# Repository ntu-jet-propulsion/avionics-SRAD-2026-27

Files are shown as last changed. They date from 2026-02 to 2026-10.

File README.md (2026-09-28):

Layers and stackup
TLB is a 4-layer, 50 × 50 mm PCB.
#	Layer	Material	Thickness	Use
—	Top silkscreen	—	—	Reference designators / labels
—	Top solder mask	—	—	—
1	F.Cu	Copper	0.035 mm	Components + signal routing
—	Prepreg	FR4	0.10 mm	Dielectric
2	In1.Cu	Copper	0.0175 mm	Split +3V3 / +5V power plane
—	Core	FR4	1.24 mm	Dielectric
3	In2.Cu	Copper	0.0175 mm	GND plane
—	Prepreg	FR4	0.10 mm	Dielectric
4	B.Cu	Copper	0.035 mm	Debugging / signal routing
—	Bottom solder mask	—	—	—
	Total		1.565 mm	

Layer strategy
- F.Cu: all components + primary signal routing
- In1.Cu: split power plane containing +3V3 and +5V
- In2.Cu: solid GND plane
- B.Cu: remaining/debug signal routing
Unlike the other board, your TLB deliberately has a power layer, because the design contains both 3.3 V and 5 V circuitry.
Your antenna keepout around the ESP32 must remain clear of routing/copper.
2. Routing rules
Your current PCB rules are:
Rule	TLB value
Minimum clearance	0.20 mm
Minimum track width	0.20 mm
Default signal track	0.25 mm
Power track	0.50 mm
Minimum via diameter	0.50 mm
Default via	0.60 / 0.30 mm
Power via	0.80 / 0.40 mm
Minimum drill	0.30 mm
Copper-edge clearance	0.50 mm
Hole-hole clearance	0.25 mm
Annular width	0.10 mm

Your net classes are:
Default
- Clearance: 0.20 mm
- Track: 0.25 mm
- Via: 0.60 / 0.30 mm
Power
- Clearance: 0.20 mm
- Track: 0.50 mm
- Via: 0.80 / 0.40 mm
- Assigned to +3V3 and +5V
3. Copper weights
Layer	Thickness	Weight
F.Cu	35 µm	1 oz
In1.Cu	17.5 µm	0.5 oz
In2.Cu	17.5 µm	0.5 oz
B.Cu	35 µm	1 oz

This matches the stackup specification you were given: 1 oz outer copper and 0.5 oz inner copper.
4. Connectors
Your TLB has these main external interfaces:
Ref	Connector	Purpose
J1	Power_In, 1×2	+3V3 power input + GND
J2	Light_APRS, 1×4	UART telemetry interface
J3	CAN connector, 1×2	CANH + CANL
J5	Micro-USB	USB interface / VBUS / shield
—	ESP32	Main controller / telemetry and logging processing

J1 — Power input
- Pin 1 → +3V3
- Pin 2 → GND
C2, the 33 µF bulk capacitor, is placed close to J1.
J2 — Light APRS
Pin	Signal
1	+3V3
2	GND
3	TX0
4	RX0

Used as the UART interface to the Light APRS system.
J3 — CAN
Pin	Signal
1	CANH
2	CANL

R4 = 120 Ω CAN termination resistor.
J5 — Micro-USB
- Pin 1 → VBUS
- Pin 5 → GND
- Pin 6 → Shield
- R6 = 0 Ω from shield to GND
- C13 associated with VBUS
- C12 associated with GND
5. Main components
MCU
U2 — ESP32-C3
Main microcontroller for the TLB.
Relevant interfaces:
ESP32 signal	Function
IO21 / TXD	I²C SCL
IO20 / RXD	I²C SDA
IO4	CAN-related
IO5	CAN-related
UART0 TX	TX0 → Light APRS
UART0 RX	RX0 ← Light APRS

The ESP32 operates from +3V3.
There is also an antenna keepout region around the ESP32 antenna.
EEPROM
U3 — 24LC256
256-kbit I²C EEPROM used for non-volatile data storage.
Connections:
- VCC → +3V3
- GND → GND
- SDA → ESP32 SDA
- SCL → ESP32 SCL
Pull-ups:
- R1 = 4.7 kΩ
- R3 = 4.7 kΩ
Decoupling:
- C5 = 0.1 µF
- C6 = 0.1 µF
CAN transceiver
U4 — TJA1051TK/3
Provides the physical-layer CAN interface.
Important power arrangement:
Pin	Function	TLB connection
1	TXD	CANTX
2	GND	GND
3	VCC	+5V
4	RXD	CANRX
5	VIO	+3V3
6	CANL	CANL
7	CANH	CANH
8	S	R2

This is important because the TJA1051TK/3 uses 5 V for VCC, while its logic interface can use 3.3 V through VIO.
Supporting components:
- C7 = 0.1 µF
- C8 = 0.1 µF
- C9 = 0.1 µF
- R2 = 10 kΩ
- R4 = 120 Ω termination
6. TLB component summary
Ref	Component	Function
U2	ESP32-C3	Main MCU
U3	24LC256	EEPROM / non-volatile storage
U4	TJA1051TK/3	CAN transceiver
J1	1×2 Power_In	+3V3 + GND input
J2	1×4 Light_APRS	UART telemetry
J3	1×2 CAN	CANH / CANL
J5	Micro-USB	USB interface
C2	33 µF	Bulk supply capacitor
C3/C4	0.1 µF	ESP32 decoupling
C5/C6	0.1 µF	EEPROM decoupling
C7/C8/C9	0.1 µF	CAN transceiver decoupling
C12/C13	0.1 µF	USB-related capacitors
R1/R3	4.7 kΩ	I²C pull-ups
R2	10 kΩ	CAN transceiver S
R4	120 Ω	CAN termination
R5	10 kΩ	ESP32 EN pull-up
R6	0 Ω	USB shield → GND

7. Interfaces / signal map
This is probably one of the most useful sections to have in your README.
I²C
ESP32 → 24LC256
- SCL → U3 pin 6
- SDA → U3 pin 5
- R1/R3 = 4.7 kΩ pull-ups to +3V3
CAN
ESP32 → TJA1051 → CAN connector
ESP32 CANTX
     ↓
TJA1051 TXD
     ↓
CAN transceiver
     ↓
CANH / CANL
     ↓
J3

and
J3 CANH / CANL
       ↓
TJA1051
       ↓
CANRX / CANTX
       ↓
ESP32

UART / Light APRS
ESP32 UART0 TX → J2 TX0
ESP32 UART0 RX ← J2 RX0

USB
J5 USB
 ├── VBUS
 ├── GND
 └── Shield

8. Power architecture
Your current PCB has:
+3V3
Used by:
- ESP32-C3
- 24LC256
- TJA1051 VIO
- I²C pull-ups
- J2
- various decoupling capacitors
+5V
Used by:
- TJA1051 VCC
GND
- Solid plane on In2.Cu
- GND vias connect component/connector GNDs into the plane.
⚠️ Important unresolved point
Your current PCB has a +5V isolated-copper warning, and we couldn't identify an obvious +5V source from the current connector arrangement:
- J1 supplies +3V3
- J5 VBUS is its own Net-(J5-VBUS) net
- U4 requires +5V at VCC
So this should remain explicitly documented as something to confirm with your team lead, rather than us inventing a power architecture.
9. Dimensions
Specification	TLB
Board width	50.0 mm
Board height	50.0 mm
Thickness	1.565 mm nominal stackup
Layers	4
Component side	Top
Mounting holes	2 × Ø5.0 mm NPTH

Your board outline is:
X = 100 → 150 mm
Y = 60 → 110 mm
giving exactly:
50 × 50 mm
10. Mounting holes
You added:
- 2 × 5 mm NPTH mounting holes
These were added as a team requirement.
The exact hole coordinates aren't in the information I have here, so I would not put coordinates into the README until we read them directly from your PCB file.
11. Protection / design features
Your TLB currently has:
Decoupling
Local 0.1 µF capacitors are placed around:
- ESP32
- EEPROM
- CAN transceiver
- USB section
CAN termination
R4 = 120 Ω between CANH and CANL.
Ground plane
In2.Cu = GND plane, with GND vias from components/connectors.
ESP32 antenna keepout
A dedicated keepout is maintained around the ESP32 antenna region.
USB shield grounding
R6 provides the shield-to-GND connection.

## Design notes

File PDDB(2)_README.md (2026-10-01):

[PDDB.md](https://github.com/user-attachments/files/32892513/PDDB.md)
# PDDB — Power Distribution & Driver Board

A **4-layer, 33.1 × 27.0 mm power board** combining a battery input with fuse, an **LM25085 P-FET buck controller**, an **LM3940 3.3 V LDO**, a **TJA1051 CAN transceiver**, and **two low-side AO3400A MOSFET drivers for nichrome coils**.

> **Status:** ⚠️ Prototype / Pre-Fabrication
> The layout is complete and passes KiCad DRC with **0 errors, 0 warnings and 0 unconnected items**. The **schematic still has functional errors**, though. Read the [Known Issues](#10-known-issues--to-do-before-ordering) section before sending the design for fabrication.

---

## 1. Board Overview

### Key Features

* Battery / power input through a screw terminal (J1) and two 1×4 headers (J2, J5)
* Fused battery path (F1)
* LM25085 constant-on-time P-FET buck controller with CSD25402Q3A P-MOSFET and 10 mΩ current sense
* LM3940 3.3 V low-dropout regulator
* TJA1051T CAN transceiver with on-board 120 Ω termination
* Two AO3400A low-side switches for nichrome coils (J7, J8)
* 4-layer PCB with a dedicated solid GND plane and a VCC power plane
* All components mounted on the top side (single-sided SMT assembly)

### Layout Statistics

| Parameter | Value |
| --- | --- |
| Board size | **33.1 × 27.0 mm** (894 mm²)  |
| Copper layers | 4 |
| Components | 35 |
| Routable nets | 19 (100 % routed) |
| Unrouted nets | 0 |
| Total vias | 63 (6 signal/power, 57 GND) |
| Total track length | ≈ 320 mm |
| DRC errors / warnings | **0 / 0** |
| Schematic parity issues | 0 |
| EDA tool | KiCad 10.0 |

---

## 2. PCB Stackup

The PCB uses a **4-layer stackup** with a nominal finished thickness of **1.6 mm**.

| Layer | Type | Thickness | Purpose |
| --- | --- | ---: | --- |
| Top | F.Cu | 35 µm | Components, signal and power routing, GND pour |
| Inner 1 | In1.Cu | 35 µm | **Solid GND plane** |
| Inner 2 | In2.Cu | 35 µm | **VCC power plane** (nichrome coil supply) + secondary routing |
| Bottom  | B.Cu | 35 µm | Secondary signal routing, GND pour |

### Dielectric Structure

| Material | Thickness |
| --- | ---: |
| Top solder mask | 0.01 mm |
| Prepreg | 0.10 mm |
| FR4 core | 1.24 mm |
| Prepreg | 0.10 mm |
| Bottom solder mask | 0.01 mm |
| **Finished thickness** | **1.60 mm** |

FR4 dielectric assumptions:

* Relative permittivity, εr: **4.5**
* Loss tangent, tan δ: **0.02**

> **Note:** These are KiCad's default 4-layer stackup values. The board file does not store an explicit stackup. Define it in *Board Setup → Physical Stackup* and confirm it with the manufacturer.

### Layer Strategy

Components and most routing are on F.Cu. **In1.Cu is an unbroken GND plane** directly under the top layer, so every top-layer signal has a reference plane immediately beneath it.

This provides:

* Short, low-impedance return paths
* Low loop area in the buck converter's switching path
* Reduced EMI
* Shielding between the top layer and the inner power plane

**In2.Cu is a VCC plane.** VCC is the nichrome coil supply. It reaches J2, J5, J7 and J8 through the plane and through 1.0 mm traces. A single Vbat trace and a single U1-VCC trace also run on In2.

**F.Cu and B.Cu carry GND pours** with island removal. Stitching vias on a ≥ 3.5 mm grid tie the pours to the inner GND plane.

### Routing Rules

| Net class | Nets | Track width | Via (pad / drill) |
| --- | --- | ---: | ---: |
| Power | VCC, J7-Pin2, J8-Pin2 (coil supply and returns) | 1.00 mm | 0.80 / 0.40 mm |
| Supply | Vbat, SW node (D1-K), Vout (C1-Pad1), +3.3 V, J2-Pin1, sense+ | 0.50 mm | 0.60 / 0.30 mm |
| Sense | U1-ISEN | 0.40 mm | 0.60 / 0.30 mm |
| Gnd | GND fan-outs (SMD pad → plane) | 0.40 mm | 0.60 / 0.30 mm |
| Default | CANH, CANL, gate drive, ADJ, feedback | 0.25 mm | 0.60 / 0.30 mm |

| Parameter | Specification |
| --- | --- |
| Minimum clearance | 0.20 mm (0.12 mm local override on U4 pads 1–4) |
| Copper-to-edge | ≥ 0.50 mm |
| Standard via | 0.60 mm pad / 0.30 mm drill |
| Small via | 0.50 mm pad / 0.25 mm drill (3 vias, U1–U4 channel) |
| Minimum drill | **0.20 mm** (U1 footprint thermal vias) |
| Minimum annular ring | 0.125 mm |
| Via type | Through-hole only (no blind / buried vias) |
| Surface finish | **ENIG recommended** |

> **Fabrication note:** U1's library footprint (MSOP-8-1EP with thermal vias) has **0.20 mm drills**, so the board minimum hole size is set to 0.20 mm. Most 4-layer fab services support this, but check before ordering.
>
> **Fabrication note:** The U4 (VSON-8 NexFET) library footprint has a 0.14 mm pad-to-pad gap at 0.65 mm pitch. A 0.12 mm local clearance is applied to those pads only. Confirm that the fab's minimum spacing is ≤ 0.12 mm.

### Surface Finish

**ENIG (Electroless Nickel Immersion Gold)** is recommended. The board has fine-pitch leadless packages (VSON-8, MSOP-8 with exposed pad) that benefit from a flat, consistent surface.

---

## 3. Copper Weight

All four copper layers use **1 oz copper (35 µm)**.

| Layer  | Copper Thickness | Copper Weight |
| --- | ---: | ---: |
| F.Cu | 35 µm | 1 oz |
| In1.Cu | 35 µm | 1 oz |
| In2.Cu | 35 µm | 1 oz |
| B.Cu | 35 µm | 1 oz |

Most of the circuitry carries low current: the controller, LDO, CAN and gate drive.

The **nichrome coil paths** are different. They run VCC → J7/J8 → coil → Q3/Q2 → GND and can carry several amps.

* VCC is carried by the In2 plane plus 1.0 mm traces.
* Drain traces Q3 → J7.2 and Q2 → J8.2 are **1.0 mm wide and only ≈ 3 mm long**.
* A 1.0 mm, 1 oz external trace handles roughly **2.5–3 A at a 10 °C rise** (IPC-2221 estimate).

> **Fabrication note:** If the coil firing current exceeds ≈ 3 A continuous, specify **2 oz outer copper**. Firing pulses are short, which also helps. Some manufacturers default to 0.5 oz on inner layers, so specify **1 oz on all four layers** to match the design.

---

## 4. Connectors and Interfaces

| Ref. | Connector / Interface | Purpose |
| --- | --- | --- |
| **J1** | Phoenix PT 1,5/2-5.0-H, 2-pin screw terminal | Battery input (GND / VBAT) |
| **J2** | 1×4, 2.54 mm header | Battery and input (fused path) |
| **J5** | 1×4, 2.54 mm header | Battery and input (parallel to J2) |
| **J4** | 1×2, 2.54 mm header | CANH / CANL |
| **J7** | 1×2, 2.54 mm header | Nichrome coil 1 (driven by Q3) |
| **J8** | 1×2, 2.54 mm header | Nichrome coil 2 (driven by Q2) |
| **J3** | 1×1, 2.54 mm pin | Unconnected in schematic |
| **J6** | 1×1, 2.54 mm pin | Unconnected in schematic |

### J1 — Battery Terminal

The screw terminal takes the main battery input. Its wire-entry face is flush with the **bottom board edge**, and silkscreen labels **GND** (pin 1) and **VBAT** (pin 2) mark the polarity.

> ⚠️ J1 pin 2 connects to Vbat **directly, without going through F1**. Only the J2/J5 path is fused.

### J2 / J5 — Battery and Input Headers

J2 and J5 are wired in parallel:

* Pin 1 is the battery input. It passes through **F1** to Vbat and also biases the coil-driver gates through R1/R5.
* Pin 2 is the VCC coil supply.
* Pins 3–4 are GND.

### J4 — CAN Bus

J4 provides the external **CANH/CANL** connection to other avionics modules.

A **120 Ω termination resistor (R4)** is fitted, so this board is intended to sit at one end of the CAN bus.

> ⚠️ **Review:** J4 only provides CANH and CANL. A shared ground reference is recommended between CAN nodes. Consider a **3-pin CANH/CANL/GND connector**.

### J7 / J8 — Nichrome Coils

Each coil connects between **VCC (pin 1)** and a **low-side AO3400A drain (pin 2)**. Each MOSFET sits directly beside its connector, keeping the switched loop short.

For flight use, consider replacing the 2.54 mm headers with locking connectors such as **JST-GH** or **Molex Pico-Lock**.

### Deliberately Absent Interfaces

The board currently does not include:

* **Microcontroller interface:** the coil drivers have no logic-level control input (see Known Issues).
* **CAN TXD/RXD connection:** the transceiver's logic pins are not brought out.
* **Mounting holes.**

---

## 5. Functional Blocks and Key Devices

| Ref. | Device | Function | Package |
| --- | --- | --- | --- |
| **U1** | TI LM25085MY | P-FET buck controller | MSOP-8-EP (PowerPAD) |
| **U4** | TI CSD25402Q3A | P-channel MOSFET (buck high-side switch) | VSON-8 3.3 × 3.3 NexFET |
| **Rsen1** | 10 mΩ | Buck current-sense resistor | 2512 |
| **L1** | 1.2 µH | Buck inductor | 7.3 × 7.3 × 4.5 mm |
| **D1** | Schottky | Buck freewheel diode | SOD-523 |
| **C2** | 100 µF | Buck output bulk capacitor | Elec. 6.3 × 5.4 mm |
| **VR1** | TI LM3940IMP-3.3 | 3.3 V LDO | SOT-223 |
| **U2** | NXP TJA1051T | High-speed CAN transceiver | SOIC-8 |
| **Q2/Q3** | AO3400A | N-channel low-side coil switches | SOT-23 |
| **F1** | Fuse | Input protection for the J2/J5 path | 1206 |

### Buck Converter (U1, U4, Rsen1, L1, D1, C2)

The LM25085 drives the CSD25402Q3A P-FET through **PGATE**. Current is sensed across **Rsen1 (10 mΩ)**: the sense+ node goes to ADJ via Radj1/Cadj1, and ISEN connects at Rsen1 pad 1.

Layout notes:

* The gate-drive trace (U1.6 → U4.4) is **3.0 mm** long.
* The ADJ trace is **3.6 mm** long. Radj1/Cadj1 sit right beside U1 pin 1.
* The switch node (U4 drain → D1 → L1) is a short **1.0 mm** copper path.
* C2 sits directly under L1's output pad, and C3 is close by.
* U1's VIN, VCC and ISEN pins escape through three 0.5 mm vias in a 1.6 mm channel between U1 and U4.

> ⚠️ The buck converter is **not functional as drawn** (see Known Issues 1 and 3).

### 3.3 V LDO (VR1, C5, C4)

The LM3940 provides a 3.3 V rail, with **C5 (33 µF)** as output capacitor.

> ⚠️ VR1's input pin is tied to GND in the schematic (see Known Issues 2).

### CAN Transceiver (U2, R4)

U2 sits directly above J4. Its CANL and CANH pins (6 and 7) line up with J4 pins 2 and 1, so the bus traces need no crossings. **R4 = 120 Ω** terminates the bus.

### Nichrome Coil Drivers (Q2, Q3, R1–R3, R5)

| Coil | Connector | MOSFET | Gate resistor | Pulled-to-GND resistor |
| ---- | --- | --- | --- | --- |
| 1 | J7 | Q3 | R5 (10 kΩ) | — |
| 2 | J8 | Q2 | R1 (10 kΩ) | — |

R2 and R3 (10 kΩ) connect **J2-Pin1 directly to GND**, not to the gates (see Known Issues 6).

---

## 6. Protection and Reliability

## Implemented Protection

| Feature | Device / Implementation | Purpose |
| --- | --- | --- |
| Input fuse | F1 (1206) | Protects the J2/J5 battery path |
| Current sensing | Rsen1 + LM25085 ADJ | Buck cycle-by-cycle current limit |
| CAN protection | TJA1051 | Bus-fault tolerance, thermal shutdown |
| CAN termination | R4 = 120 Ω | Bus termination |
| Ground plane | In1.Cu (solid) + F/B GND pours  | Low-impedance return, EMI reduction |
| Power plane | In2.Cu VCC | Low-impedance coil supply |
| Local decoupling | Cadj2/Cadj3, C3, C5 | Supply filtering |

### Fuse

**F1** sits between J2/J5 pin 1 and the Vbat net.

> ⚠️ The J1 screw terminal feeds Vbat **directly and bypasses F1**. Consider moving F1 so it protects all inputs.

### CAN Protection

**U2 — TJA1051T** provides built-in protection against bus faults.

> ⚠️ No external CAN ESD/TVS protection is fitted. Because J4 connects to an external cable, consider adding a CAN TVS (e.g. PESD2CAN).

### Ground and Power Planes

* **In1.Cu** is a solid GND plane. The only openings are via and pad clearances.
* Every SMD ground pad has its **own fan-out via** to In1.
* **F.Cu and B.Cu** carry GND pours, stitched to In1 with vias.
* **In2.Cu** is the VCC (coil supply) plane.

---

## Protection Not Currently Implemented

The following protection features are absent or incomplete:

* ❌ Reverse-polarity protection
* ❌ Fuse on the J1 input path
* ❌ CAN external TVS/ESD protection
* ❌ Gate pull-down resistors on Q2/Q3 (coils could turn on from a floating gate)
* ❌ Gate-voltage clamp on Q2/Q3: AO3400A V<sub>GS</sub> max is ±12 V, and the gates are fed from the battery input
* ❌ Flyback / snubber across the coil outputs
* ❌ Input TVS / transient protection

Review these against the final battery voltage and system requirements.

---

## 7. Board Dimensions

| Parameter | Specification |
| --- | --- |
| Board size | **33.1 × 27.0 mm** |
| Board thickness | **1.6 mm** |
| Board shape | Rectangular |
| Component placement | Top side only |
| Mounting holes | **None** (not in schematic) |

### Connector Locations

Coordinates are pin-1 positions, measured from the **top-left corner** of the PCB:

| Connector | Edge | X | Y |
| --- | --- | ---: | ---: |
| J7 | Right  | 31.3 mm |  1.8 mm |
| J8 | Right  | 31.3 mm |  8.0 mm |
| J5 | Right  | 31.3 mm | 17.6 mm |
| J1 | Bottom |  3.0 mm | 21.0 mm |
| J2 | Bottom | 12.9 mm | 25.2 mm |
| J4 | Bottom | 26.7 mm | 25.2 mm |
| J6 | Inner  | 11.0 mm | 12.6 mm |
| J3 | Inner  | 17.6 mm | 21.5 mm |

> ⚠️ The board has **no mounting holes**. If it has to be mechanically secured, add M2/M2.5 holes. That would make the board larger, roughly +6 mm in each direction for corner holes.

### Tall Components

| Component | Approx. Height |
| --- | ---: |
| J2, J4, J5, J7, J8, J3, J6 (2.54 mm headers) | ≈ 8.5 mm (standard 6 mm mating pin) |
| J1 screw terminal | Refer to Phoenix PT 1,5/2-5.0-H datasheet |
| C2 electrolytic | 5.4 mm |
| L1 inductor | 4.5 mm |

---

## 8. Connector Pin Map

| Connector | Pin | Net | Connected To |
| --- | --- | --- | --- |
| J1 | 1 | GND | Ground plane |
| J1 | 2 | Vbat | U1 VIN, Cadj2, Cadj3, Radj2, F1.1 ⚠️ unfused  |
| J2 / J5 | 1 | J2-Pin_1 | F1 → Vbat; R1, R5 (gates); R2, R3 (to GND) ⚠️ |
| J2 / J5 | 2 | VCC | J7.1, J8.1 (coil supply, In2 plane) |
| J2 / J5 | 3 | GND | Ground plane |
| J2 / J5 | 4 | GND | Ground plane |
| J4 | 1 | CANH | U2 pin 7, R4 |
| J4 | 2 | CANL | U2 pin 6, R4 |
| J7 | 1 | VCC | Coil 1 supply |
| J7 | 2 | J7-Pin_2 | Q3 drain |
| J8 | 1 | VCC | Coil 2 supply |
| J8 | 2 | J8-Pin_2 | Q2 drain |
| J3 | 1 | — | Unconnected ⚠️ |
| J6 | 1 | — | Unconnected ⚠️ |

⚠️ = requires review before fabrication.

---

## 9. Footprint Library

Every footprint comes from the **official KiCad footprint library** (`kicad-footprints`, KiCad 10). DRC reports no library mismatches, so the board copies are identical to the library versions.

| Ref(s) | Footprint | Library Link |
| --- | --- | --- |
| U1 | `Package_SO:MSOP-8-1EP_3x3mm_P0.65mm_EP1.73x1.85mm_ThermalVias` | [kicad_mod](https://gitlab.com/kicad/libraries/kicad-footprints/-/blob/master/Package_SO.pretty/MSOP-8-1EP_3x3mm_P0.65mm_EP1.73x1.85mm_ThermalVias.kicad_mod) |
| U2 | `Package_SO:SOIC-8_3.9x4.9mm_P1.27mm` | [kicad_mod](https://gitlab.com/kicad/libraries/kicad-footprints/-/blob/master/Package_SO.pretty/SOIC-8_3.9x4.9mm_P1.27mm.kicad_mod) |
| U4 | `Package_SON:VSON-8_3.3x3.3mm_P0.65mm_NexFET` | [kicad_mod](https://gitlab.com/kicad/libraries/kicad-footprints/-/blob/master/Package_SON.pretty/VSON-8_3.3x3.3mm_P0.65mm_NexFET.kicad_mod) |
| VR1 | `Package_TO_SOT_SMD:SOT-223` | [kicad_mod](https://gitlab.com/kicad/libraries/kicad-footprints/-/blob/master/Package_TO_SOT_SMD.pretty/SOT-223.kicad_mod) |
| Q2, Q3 | `Package_TO_SOT_SMD:SOT-23` | [kicad_mod](https://gitlab.com/kicad/libraries/kicad-footprints/-/blob/master/Package_TO_SOT_SMD.pretty/SOT-23.kicad_mod) |
| D1 | `Diode_SMD:D_SOD-523` | [kicad_mod](https://gitlab.com/kicad/libraries/kicad-footprints/-/blob/master/Diode_SMD.pretty/D_SOD-523.kicad_mod) |
| L1 | `Inductor_SMD:L_7.3x7.3_H4.5` | [kicad_mod](https://gitlab.com/kicad/libraries/kicad-footprints/-/blob/master/Inductor_SMD.pretty/L_7.3x7.3_H4.5.kicad_mod) |
| C2 | `Capacitor_SMD:CP_Elec_6.3x5.4` | [kicad_mod](https://gitlab.com/kicad/libraries/kicad-footprints/-/blob/master/Capacitor_SMD.pretty/CP_Elec_6.3x5.4.kicad_mod) |
| C5 | `Capacitor_SMD:C_1206_3216Metric` | [kicad_mod](https://gitlab.com/kicad/libraries/kicad-footprints/-/blob/master/Capacitor_SMD.pretty/C_1206_3216Metric.kicad_mod) |
| C1, C3, C4 | `Capacitor_SMD:C_0805_2012Metric` | [kicad_mod](https://gitlab.com/kicad/libraries/kicad-footprints/-/blob/master/Capacitor_SMD.pretty/C_0805_2012Metric.kicad_mod) |
| Cadj1, Cadj2, Cadj3 | `Capacitor_SMD:C_0603_1608Metric` | [kicad_mod](https://gitlab.com/kicad/libraries/kicad-footprints/-/blob/master/Capacitor_SMD.pretty/C_0603_1608Metric.kicad_mod) |
| Rsen1 | `Resistor_SMD:R_2512_6332Metric` | [kicad_mod](https://gitlab.com/kicad/libraries/kicad-footprints/-/blob/master/Resistor_SMD.pretty/R_2512_6332Metric.kicad_mod) |
| R1, R2, R3, R5, R6, R7 | `Resistor_SMD:R_0805_2012Metric_Pad1.20x1.40mm_HandSolder` | [kicad_mod](https://gitlab.com/kicad/libraries/kicad-footprints/-/blob/master/Resistor_SMD.pretty/R_0805_2012Metric_Pad1.20x1.40mm_HandSolder.kicad_mod) |
| R4, Radj1, Radj2 | `Resistor_SMD:R_0603_1608Metric` | [kicad_mod](https://gitlab.com/kicad/libraries/kicad-footprints/-/blob/master/Resistor_SMD.pretty/R_0603_1608Metric.kicad_mod) |
| F1 | `Fuse:Fuse_1206_3216Metric` | [kicad_mod](https://gitlab.com/kicad/libraries/kicad-footprints/-/blob/master/Fuse.pretty/Fuse_1206_3216Metric.kicad_mod) |
| J1 | `TerminalBlock_Phoenix:TerminalBlock_Phoenix_PT-1,5-2-5.0-H_1x02_P5.00mm_Horizontal` | [kicad_mod](https://gitlab.com/kicad/libraries/kicad-footprints/-/blob/master/TerminalBlock_Phoenix.pretty/TerminalBlock_Phoenix_PT-1,5-2-5.0-H_1x02_P5.00mm_Horizontal.kicad_mod) |
| J2, J5 | `Connector_PinHeader_2.54mm:PinHeader_1x04_P2.54mm_Vertical` | [kicad_mod](https://gitlab.com/kicad/libraries/kicad-footprints/-/blob/master/Connector_PinHeader_2.54mm.pretty/PinHeader_1x04_P2.54mm_Vertical.kicad_mod) |
| J4, J7, J8 | `Connector_PinHeader_2.54mm:PinHeader_1x02_P2.54mm_Vertical` | [kicad_mod](https://gitlab.com/kicad/libraries/kicad-footprints/-/blob/master/Connector_PinHeader_2.54mm.pretty/PinHeader_1x02_P2.54mm_Vertical.kicad_mod) |
| J3, J6 | `Connector_PinHeader_2.54mm:PinHeader_1x01_P2.54mm_Vertical` | [kicad_mod](https://gitlab.com/kicad/libraries/kicad-footprints/-/blob/master/Connector_PinHeader_2.54mm.pretty/PinHeader_1x01_P2.54mm_Vertical.kicad_mod) |

Library home: [gitlab.com/kicad/libraries/kicad-footprints](https://gitlab.com/kicad/libraries/kicad-footprints)

> **Board-level modification:** U4 pads 1–4 have a **0.12 mm local clearance** set on the board. The footprint geometry itself is unchanged.

---

# 10. Known Issues / To-Do Before Ordering

> ⚠️ **Do not send the PCB for fabrication until the following issues have been reviewed and resolved.**
> All of them are **schematic** issues. The netlist was deliberately left unchanged during layout so the board stays in sync with the schematic. Fix the schematic, update the PCB from it, and re-route the affected nets.

## 10.1 Critical Functional Issues

### 1. Buck Converter Input Path Is Open

The sense+ node is not connected to **Vbat**. This node is Rsen1 pin 2 / Radj1 pin 2 / Cadj1 pin 1 (`Net-(Cadj1-Pad1)`), so U4's source has no supply and the converter cannot run.

**Action:** Connect the Rsen1 / Radj1 / Cadj1 node to Vbat (the LM25085 VIN side), as in the datasheet's typical application.

---

### 2. LM3940 Input Grounded

VR1 pins 1 and 2 are both on GND, and the tab (pin 4) is unconnected. On the SOT-223 LM3940, **pin 1 is IN**. The +3.3 V rail can never be powered.

**Action:** Connect VR1 pin 1 to the intended input rail (5 V or the buck output) and the tab to GND.

---

### 3. LM25085 FB Unconnected

U1 pin 3 (FB) is unconnected, so the R7/R6/C1 feedback divider does not reach the controller.

**Action:** Connect the R7/R6 junction (`Net-(C1-Pad2)`) to U1 FB.

---

### 4. LM25085 Exposed Pad Unconnected

U1's exposed pad (pin 9) and its thermal vias are not on GND.

**Action:** Tie EP to GND per the datasheet.

---

### 5. CAN Transceiver Supply and Logic

U2 VCC (pin 3) is fed from `Net-(U1-VCC)`. That is the LM25085's VCC gate-drive bias pin, **not a regulated 5 V rail**. The TJA1051 needs **4.5–5.5 V**.

U2's other pins are also open:

* TXD (pin 1) is unconnected
* RXD (pin 4) is unconnected
* S (pin 8) is unconnected

**Action:** Provide a proper 5 V supply with local decoupling. Bring TXD/RXD to a controller. Tie S to GND for normal mode, or drive it.

---

### 6. Coil Driver Gate Network

R2 and R3 are connected **from J2-Pin1 to GND**, not from the gates to GND. As drawn:

* Q2/Q3 gates are pulled to the battery input through R1/R5, with no pull-down, so both coils energise whenever J2/J5 pin 1 is live.
* The AO3400A gate rating (±12 V) can be exceeded on a higher-voltage battery.

**Action:** Confirm the intended control scheme. Most likely R2/R3 should be gate pull-downs, and the gates should be driven by a logic-level control signal. Add gate clamping if the battery voltage exceeds 12 V.

---

### 7. Unfused J1 Input

J1 pin 2 feeds Vbat directly, bypassing F1.

**Action:** Route all battery inputs through the fuse.

---

## 10.2 Design Review Items

### C4 Shorted to Ground

C4 has both pads on GND, so it does nothing.

**Action:** Fix its connection or mark it **DNP**.

### Freewheel Diode Rating

D1 is in a **SOD-523** package, which is only rated for low current.

**Action:** Check D1's current rating against the buck converter's load current. A SOD-123F/SMA Schottky may be needed.

### Unconnected Pins J3 / J6

J3 and J6 have no net.

**Action:** Assign their intended function or remove them.

### Unspecified Values

The following values need confirming:

* R7: value shown as `R_Small_US`
* F1: rating not specified
* D1: part number not specified

### Mounting

No mounting holes are present.

**Action:** Add them if the board must be mechanically fixed.

---

# 11. PCB Housekeeping

Before generating manufacturing files:

* [ ] Define the physical stackup explicitly in *Board Setup* (currently KiCad defaults).
* [ ] Add mounting holes if required.
* [ ] Re-run placement and routing for the nets that change after the schematic fixes.
* [ ] Verify silkscreen labels. Refdes for U1, R3, Radj1/2 and Cadj1/2 are on F.Fab only (no room on silk).
* [ ] Check component courtyard clearance (currently 0 violations).
* [ ] Run **Electrical Rules Check (ERC)**.
* [ ] Run **Design Rules Check (DRC)** (currently 0 errors / 0 warnings).
* [ ] Refill all zones before plotting.
* [ ] Generate and inspect Gerbers and drill files before fabrication.

---

# 12. Pre-Fabrication Checklist

### Electrical

* [ ] Buck input path (sense+ → Vbat) connected
* [ ] Buck FB connected and output voltage verified
* [ ] LM25085 exposed pad tied to GND
* [ ] LM3940 input / tab corrected
* [ ] CAN transceiver 5 V supply provided
* [ ] CAN TXD/RXD/S connected
* [ ] CAN termination verified
* [ ] Coil gate drive and pull-downs corrected
* [ ] Gate-voltage rating checked against battery voltage
* [ ] All inputs fused
* [ ] D1 current rating verified
* [ ] Protection requirements reviewed

### PCB

* [ ] Stackup confirmed with manufacturer
* [ ] 1 oz copper specified on all layers (2 oz outer if coil current > ~3 A)
* [ ] 0.20 mm minimum drill supported by fab
* [ ] 0.12 mm minimum spacing (U4 pads) supported by fab
* [ ] Surface finish specified (ENIG)
* [ ] Board dimensions verified (33.1 × 27.0 mm)
* [ ] Mounting holes added or confirmed not required
* [ ] Connector footprints verified
* [ ] Component clearances checked
* [ ] DRC passed
* [ ] ERC passed

### Documentation

* [ ] BOM updated
* [ ] Part numbers verified
* [ ] Connector specifications confirmed
* [ ] Revision number updated
* [ ] Schematic revision updated
* [ ] PCB revision updated
* [ ] README updated
* [ ] Gerbers generated
* [ ] Gerbers reviewed

---

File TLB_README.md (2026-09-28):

# TLB 

A **4-layer, 50 × 50 mm PCB** designed around an **ESP32-C3**. The TLB provides UART telemetry, CAN communication, non-volatile EEPROM storage, USB connectivity, and regulated 3.3 V / 5 V power domains.

> **Status:** Prototype / Pre-Fabrication
> Review the [Power Architecture](#8-power-architecture) section before fabrication, particularly the unresolved +5 V supply for the CAN transceiver.

---

# 1. Layers and Stackup

The TLB is a **4-layer PCB** with a nominal finished thickness of **1.565 mm**.

| Layer | Material | Thickness | Purpose |
| --- | --- | ---: | --- |
| Top silkscreen | — | — | Reference designators and labels |
| Top solder mask | — | — | Component-side protection |
| **1 — F.Cu** | Copper | 0.035 mm | Components and primary signal routing  |
| Prepreg | FR4 | 0.10 mm | Dielectric |
| **2 — In1.Cu** | Copper | 0.0175 mm | Split **+3V3 / +5V power plane** |
| Core | FR4 | 1.24 mm | Dielectric |
| **3 — In2.Cu** | Copper | 0.0175 mm | **Solid GND plane** |
| Prepreg | FR4 | 0.10 mm | Dielectric |
| **4 — B.Cu** | Copper | 0.035 mm | Debugging and secondary signal routing |
| Bottom solder mask | — | — | Bottom-side protection |
| **Total** | | **1.565 mm** | |

### Layer Strategy

* **F.Cu:** Components and primary signal routing
* **In1.Cu:** Split power plane containing **+3V3** and **+5V**
* **In2.Cu:** Solid **GND** plane
* **B.Cu:** Secondary/debug signal routing

Unlike a board using both inner layers as ground, the TLB deliberately uses **In1.Cu as a power plane** because the design contains both 3.3 V and 5 V circuitry.

### ESP32 Antenna Keepout

A dedicated antenna keepout is maintained around the ESP32.

> ⚠️ **Do not route signals or place copper/components inside the ESP32 antenna keepout region.** Maintaining this clearance is important for reliable RF performance.

---

# 2. Routing Rules

The current PCB design uses the following routing constraints:

| Rule | TLB Value |
| --- | ---: |
| Minimum clearance | 0.20 mm |
| Minimum track width | 0.20 mm |
| Default signal track | 0.25 mm |
| Power track | 0.50 mm |
| Minimum via diameter | 0.50 mm |
| Default via | 0.60 / 0.30 mm |
| Power via | 0.80 / 0.40 mm |
| Minimum drill | 0.30 mm |
| Copper-to-edge clearance | 0.50 mm |
| Hole-to-hole clearance | 0.25 mm |
| Minimum annular width | 0.10 mm |

## Net Classes

### Default

| Parameter | Value |
| --- | ---: |
| Clearance | 0.20 mm |
| Track width | 0.25 mm |
| Via | 0.60 / 0.30 mm |

### Power

| Parameter | Value |
| --- | ---: |
| Clearance | 0.20 mm |
| Track width | 0.50 mm |
| Via | 0.80 / 0.40 mm |
| Assigned nets | +3V3, +5V |

---

# 3. Copper Weights

The PCB uses **1 oz outer copper** and **0.5 oz inner copper**.

| Layer  | Thickness | Copper Weight |
| --- | ---: | ---: |
| F.Cu | 35 µm | **1 oz** |
| In1.Cu | 17.5 µm | **0.5 oz** |
| In2.Cu | 17.5 µm | **0.5 oz** |
| B.Cu | 35 µm | **1 oz** |

This matches the intended PCB fabrication stackup.

---

# 4. Connectors and External Interfaces

The TLB provides the following main external interfaces:

| Ref. | Connector | Purpose |
| --- | --- | --- |
| **J1** | 1×2 `Power_In` | +3V3 power input and GND |
| **J2** | 1×4 `Light_APRS`  | UART telemetry interface |
| **J3** | 1×2 CAN connector | CANH and CANL |
| **J5** | Micro-USB | USB, VBUS and shield |
| — | ESP32-C3 | Main controller and telemetry processor |

## J1 — Power Input

| Pin | Signal |
| --- | --- |
| 1 | +3V3 |
| 2 | GND |

**C2 = 33 µF** provides bulk capacitance close to the power input.

---

## J2 — Light APRS

| Pin | Signal |
| --- | --- |
| 1 | +3V3 |
| 2 | GND |
| 3 | TX0 |
| 4 | RX0 |

J2 provides the UART interface to the **Light APRS** system.

---

## J3 — CAN

| Pin | Signal |
| --- | --- |
| 1 | CANH |
| 2 | CANL |

**R4 = 120 Ω** provides CAN bus termination.

---

## J5 — Micro-USB

The USB interface provides:

* **VBUS**
* **GND**
* **USB shield**

Current connections:

| USB Signal | Connection |
| --- | --- |
| VBUS | Net-(J5-VBUS) |
| GND | GND |
| Shield | R6 → GND |

Additional components:

* **R6 = 0 Ω** — USB shield to GND
* **C13 = 0.1 µF** — VBUS-related capacitor
* **C12 = 0.1 µF** — GND-related capacitor

---

# 5. Main Components

## 5.1 ESP32-C3 — U2

The **ESP32-C3** is the main microcontroller for the TLB.

It handles:

* Telemetry processing
* UART communication
* CAN communication
* EEPROM access
* Data processing and logging

The ESP32 operates from the **+3V3** rail.

### Relevant Interfaces

| ESP32 Signal | Function |
| --- | --- |
| IO21 / TXD | I²C SCL |
| IO20 / RXD | I²C SDA |
| IO4 | CAN-related |
| IO5 | CAN-related |
| UART0 TX | TX0 → Light APRS |
| UART0 RX | RX0 ← Light APRS |

> The ESP32 antenna keepout must remain free of copper, routing and components.

---

## 5.2 EEPROM — U3

**U3 — 24LC256**

The 24LC256 is a **256-kbit I²C EEPROM** used for non-volatile data storage.

### Connections

* VCC → +3V3
* GND → GND
* SDA → ESP32 SDA
* SCL → ESP32 SCL

### Supporting Components

| Component |  Value | Function |
| --- | -----: | --- |
| R1 | 4.7 kΩ | I²C pull-up |
| R3 | 4.7 kΩ | I²C pull-up |
| C5 | 0.1 µF | Decoupling  |
| C6 | 0.1 µF | Decoupling  |

---

## 5.3 CAN Transceiver — U4

**U4 — TJA1051TK/3**

The TJA1051TK/3 provides the physical-layer interface between the ESP32 and the CAN bus.

### Pin Connections

| Pin | Function | TLB Connection |
| --: | --- | --- |
| 1 | TXD | CANTX |
| 2 | GND | GND |
| 3 | VCC | +5V |
| 4 | RXD | CANRX |
| 5 | VIO | +3V3 |
| 6 | CANL | CANL |
| 7 | CANH | CANH |
| 8 | S | R2 |

### Power Architecture

The TJA1051TK/3 uses:

* **+5V for VCC**
* **+3V3 for VIO**

This allows the CAN transceiver to interface with the 3.3 V ESP32 logic while operating its main supply from 5 V.

### Supporting Components

| Component |  Value | Function |
| --- | -----: | --- |
| C7 | 0.1 µF | Decoupling |
| C8 | 0.1 µF | Decoupling |
| C9 | 0.1 µF | Decoupling |
| R2 |  10 kΩ | CAN transceiver S |
| R4 |  120 Ω | CAN termination |

---

# 6. Component Summary

| Ref. | Component | Function |
| --- | --- | --- |
| **U2** | ESP32-C3 | Main MCU |
| **U3** | 24LC256 | Non-volatile EEPROM |
| **U4** | TJA1051TK/3 | CAN transceiver |
| **J1** | 1×2 Power_In | +3V3 + GND input |
| **J2** | 1×4 Light_APRS | UART telemetry |
| **J3** | 1×2 CAN | CANH / CANL |
| **J5** | Micro-USB | USB interface |
| **C2** | 33 µF | Bulk supply capacitor |
| **C3/C4** | 0.1 µF | ESP32 decoupling |
| **C5/C6** | 0.1 µF | EEPROM decoupling |
| **C7/C8/C9** | 0.1 µF | CAN transceiver decoupling |
| **C12/C13**  | 0.1 µF | USB-related capacitors |
| **R1/R3** | 4.7 kΩ | I²C pull-ups |
| **R2** | 10 kΩ | CAN transceiver S |
| **R4** | 120 Ω | CAN termination |
| **R5** | 10 kΩ | ESP32 EN pull-up |
| **R6** | 0 Ω | USB shield → GND |

---

# 7. Interfaces and Signal Map

## I²C

The ESP32 communicates with the 24LC256 over I²C.

```text
ESP32-C3
   │
   ├── SCL ───────► U3 SCL
   │                 │
   │              R1 = 4.7 kΩ
   │                 │
   │               +3V3
   │
   └── SDA ───────► U3 SDA
                     │
                  R3 = 4.7 kΩ
                     │
                   +3V3
```

---

## CAN

The ESP32 communicates with the external CAN bus through U4.

```text
ESP32 CANTX
     │
     ▼
TJA1051 TXD
     │
     ▼
 CAN Transceiver
     │
     ├────────► CANH ──────► J3
     │
     └────────► CANL ──────► J3
```

The receive path is:

```text
J3 CANH / CANL
      │
      ▼
TJA1051
      │
      ▼
ESP32 CANRX
```

**R4 = 120 Ω** provides CAN termination between CANH and CANL.

---

## UART / Light APRS

```text
ESP32 UART0 TX ─────► J2 TX0

ESP32 UART0 RX ◄───── J2 RX0
```

J2 also provides +3V3 and GND.

---

## USB

```text
J5 Micro-USB
   │
   ├── VBUS
   ├── GND
   └── Shield
          │
        R6 = 0 Ω
          │
         GND
```

---

# 8. Power Architecture

The TLB contains the following power domains:

## +3V3

The +3V3 rail supplies:

* ESP32-C3
* 24LC256
* TJA1051 VIO
* I²C pull-ups
* J2
* Local decoupling capacitors

## +5V

The +5V rail is intended to supply:

* **TJA1051 VCC**

## GND

Ground is implemented primarily through the **In2.Cu solid ground plane**.

Ground vias connect component and connector ground pins to the plane.

---

## ⚠️ +5V Supply — To Be Confirmed

The current PCB contains a **+5V copper region**, but the source of the +5V rail is not clearly defined in the current connector arrangement.

Currently:

* **J1** provides +3V3
* **J5 VBUS** is on `Net-(J5-VBUS)`
* **U4 VCC** requires +5V

Therefore, the source and regulation path for +5V must be confirmed before fabrication.

> **Action required:** Confirm with the team whether +5V is generated elsewhere, supplied through USB VBUS, or requires an onboard regulator.

Do **not** assume the +5V power architecture is complete until this has been verified.

---

# 9. Board Dimensions

| Specification | TLB |
| --- | ---: |
| Board width | **50.0 mm** |
| Board height | **50.0 mm** |
| Nominal thickness | **1.565 mm** |
| Number of layers  | **4** |
| Component side | Top |
| Mounting holes | **2 × Ø5.0 mm NPTH** |

### Board Outline

The PCB outline is:

```text
X = 100 → 150 mm
Y = 60 → 110 mm
```

Therefore:

**Board size = 50 × 50 mm**

---

# 10. Mounting

The TLB currently contains:

* **2 × Ø5.0 mm non-plated through holes (NPTH)**

Verify the final mounting-hole positions and mechanical clearances against the intended enclosure or mounting structure before fabrication.

---

# 11. Protection and Design Features

## Local Decoupling

Local **0.1 µF decoupling capacitors** are provided around:

* ESP32-C3
* 24LC256
* TJA1051
* USB interface

These capacitors provide local high-frequency supply filtering and reduce supply noise.

## CAN Termination

**R4 = 120 Ω** is connected between CANH and CANL.

This provides termination when the TLB is installed at an end of the CAN bus.

> If the TLB is used as an intermediate CAN node, the termination resistor should be made removable or otherwise disabled.

## Ground Plane

**In2.Cu** is configured as a solid GND plane.

Ground vias connect the component and connector ground connections to the plane, providing low-impedance return paths.

## ESP32 Antenna Keepout

A dedicated keepout region is maintained around the ESP32 antenna.

No routing, copper pours or components should be placed within this region.

## USB Shield Grounding

**R6 = 0 Ω** connects the USB shield to GND.

This provides a defined shield-ground connection while allowing the connection to be modified during hardware testing if required.

---

# 12. Pre-Fabrication Checklist

Before sending the TLB for fabrication:

### PCB

* [ ] Confirm 4-layer stackup with PCB manufacturer
* [ ] Confirm 1 oz outer / 0.5 oz inner copper
* [ ] Confirm 1.565 mm finished thickness is supported
* [ ] Verify 50 × 50 mm board outline
* [ ] Verify mounting-hole locations
* [ ] Verify ESP32 antenna keepout
* [ ] Check all connector footprints
* [ ] Run DRC
* [ ] Resolve all critical DRC violations

### Electrical

* [ ] Confirm +3V3 supply
* [ ] Confirm +5V supply source
* [ ] Verify TJA1051 VCC = +5V
* [ ] Verify TJA1051 VIO = +3V3
* [ ] Verify CAN termination
* [ ] Verify I²C pull-ups
* [ ] Verify UART TX/RX connections
* [ ] Verify USB VBUS routing
* [ ] Verify all decoupling capacitors

### Documentation

* [ ] Update schematic revision
* [ ] Update PCB revision
* [ ] Update BOM
* [ ] Confirm connector part numbers
* [ ] Confirm fabrication stackup
* [ ] Confirm unresolved issues are closed
* [ ] Generate and review Gerber files

---

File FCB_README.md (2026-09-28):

# Flight Computer

A **4-layer rocket/UAV flight computer** built around a **Teensy 4.0**. The board integrates redundant inertial and barometric sensing, GNSS, a real-time clock, microSD data logging, CAN communication, and onboard status indicators.

> **Status:** ⚠️ Prototype / Pre-Fabrication
> Review the [Known Issues](#known-issues--to-do-before-ordering) section before sending the design for fabrication.

---

## 1. Board Overview

### Key Features

* **Teensy 4.0** main flight controller
* Redundant IMU and barometric sensing
* High-G accelerometer for launch/deployment events
* GNSS positioning and recovery tracking
* Real-time clock for timestamped data
* microSD flight-data logging
* CAN bus communication
* Onboard buzzer and status LED
* 4-layer PCB with dedicated ground planes
* All components mounted on the top side

---

## 2. PCB Stackup

The PCB uses a **4-layer stackup** with a nominal finished thickness of **1.6 mm**.

| Layer | Type | Thickness | Purpose |
| --- | --- | ---: | --- |
| Top | F.Cu | 35 µm | Components, signal routing, 3.3 V routing, GPS keepout |
| Inner 1 | In1.Cu | 35 µm | **Solid GND plane** |
| Inner 2 | In2.Cu | 35 µm | **Solid GND plane** |
| Bottom  | B.Cu | 35 µm | Signal routing |

### Dielectric Structure

| Material | Thickness |
| --- | ---: |
| Top solder mask | 0.01 mm |
| Prepreg | 0.10 mm |
| FR4 core | 1.24 mm |
| Prepreg | 0.10 mm |
| Bottom solder mask | 0.01 mm |
| **Finished thickness** | **1.60 mm** |

FR4 dielectric assumptions:

* Relative permittivity, εr: **4.5**
* Loss tangent, tan δ: **0.02**

### Layer Strategy

Signal routing is primarily performed on the two outer copper layers, while **both inner layers are solid ground planes**.

This provides:

* Shorter return-current paths
* Lower loop area
* Improved signal integrity
* Reduced EMI
* Better shielding between signal layers

The 3.3 V rail is routed using traces and local copper pours rather than a dedicated power plane.

### Routing Rules

| Parameter | Specification |
| --- | --- |
| Standard trace width | 0.20 mm |
| Via pad diameter | 0.60 mm |
| Via drill | 0.30 mm |
| Via type | Through-hole |
| Blind vias | 1 currently present  |
| Surface finish | **ENIG recommended** |

> **Fabrication note:** A blind via currently exists from Top → In1.Cu at approximately `(245, 29)`. Many low-cost PCB manufacturers do not support blind vias or charge additional fees. Consider converting this to a standard through-hole via before fabrication.

### Surface Finish

**ENIG (Electroless Nickel Immersion Gold)** is recommended because the board contains fine-pitch/LGA sensor packages and benefits from a flat, consistent surface.

---

## 3. Copper Weight

All four copper layers use **1 oz copper**.

| Layer  | Copper Thickness | Copper Weight |
| --- | ---: | ---: |
| F.Cu | 35 µm | 1 oz |
| In1.Cu | 35 µm | 1 oz |
| In2.Cu | 35 µm | 1 oz |
| B.Cu | 35 µm | 1 oz |

The flight computer carries relatively low current, primarily for the Teensy, sensors, GNSS, storage, and communication interfaces. Therefore, **1 oz copper is sufficient for the intended electrical loads**.

The standard 0.20 mm traces should nevertheless be reviewed against the actual current requirements of each power net before fabrication.

> **Fabrication note:** Some manufacturers default to 0.5 oz copper on inner layers. Specify **1 oz copper on all four layers** if the fabricated stackup is required to match the design.

---

# 4. Connectors and Interfaces

| Ref. | Connector / Interface | Purpose |
| --- | --- | --- |
| **J1** | Würth 693072010801 microSD socket | Flight-data storage |
| **J4** | 1×2, 2.54 mm header | CANH / CANL connection |
| — | Teensy 4.0 micro-USB | Power, programming and debugging |

### J1 — microSD

The microSD socket provides non-volatile storage for flight data.

The Teensy communicates with the card using **SPI**, allowing sensor measurements, GNSS data, system status, and other flight information to be logged during operation.

The card can be removed after recovery and read using a standard PC.

### J4 — CAN Bus

J4 provides the external **CANH/CANL** connection to other avionics modules.

Potential CAN-connected systems include:

* Recovery/pyro controller
* Power-management board
* Telemetry system
* Other flight computers or avionics modules

CAN uses differential signalling and provides good noise immunity, making it suitable for inter-board communication within a vehicle.

A **120 Ω termination resistor (R4)** is currently fitted, meaning this board is intended to operate at one end of the CAN bus.

> ⚠️ **Review:** J4 currently provides only CANH and CANL. A shared ground reference is recommended for the connected CAN nodes. Consider changing J4 to a **3-pin CANH/CANL/GND connector**.

### Teensy USB

The Teensy 4.0 micro-USB connection currently provides:

* Board power
* Firmware programming
* Serial debugging
* Development/testing access

> **Important:** USB is currently the **only power input to the board**.

### Deliberately Absent Interfaces

The board currently does not include:

* **External GPS antenna connector** — the SAM-M8Q includes an integrated patch antenna.
* **Dedicated battery connector** — the current design is powered through the Teensy USB connection.
* **Pyro/deployment outputs** — deployment circuitry is not implemented on this board.

For flight use, consider replacing the J4 2.54 mm header with a locking connector such as **JST-GH** or **Molex Pico-Lock**.

---

# 5. Sensor and Monitoring Devices

The flight computer uses multiple sensors to provide redundancy and cover different flight regimes.

| Ref. | Device | Measurement | Interface | Purpose |
| --- | --- | --- | --- | --- |
| **U9**  | Bosch BMI088 | 3-axis acceleration + 3-axis gyro | SPI | Primary IMU |
| **U2**  | Bosch BNO055 | 9-axis IMU + sensor fusion | I²C | Secondary IMU and orientation  |
| **U10** | ADXL375 | ±200 g acceleration | SPI | High-G event detection |
| **U6**  | Bosch BMP390 | Pressure + temperature | I²C | Primary altitude estimation |
| **U12** | Bosch BMP390 | Pressure + temperature | I²C | Redundant altitude measurement |
| **U4**  | u-blox SAM-M8Q | Position, velocity, time | UART | GNSS positioning |
| **U7**  | TI INA226-Q1 | Voltage, current, power | I²C | Power monitoring |
| **IC1** | DS3231 | Real-time clock | I²C | Timestamping |

### BMI088 — Primary IMU

The BMI088 provides:

* 3-axis acceleration
* 3-axis angular velocity
* High vibration tolerance

It is intended as the primary inertial measurement source during flight, particularly during high-vibration conditions.

### BNO055 — Secondary IMU

The BNO055 provides:

* 3-axis acceleration
* 3-axis angular velocity
* 3-axis magnetometer
* Onboard sensor fusion
* Quaternion/Euler orientation output

It provides an independent inertial measurement source and can be used to cross-check the BMI088.

### ADXL375 — High-G Accelerometer

The ADXL375 provides acceleration measurement up to approximately **±200 g**.

It complements the lower-range IMUs by capturing events such as:

* Launch acceleration
* High-G flight events
* Deployment shocks
* Landing impacts

### BMP390 — Barometric Altimeters

Two BMP390 devices are used for **redundant altitude measurement**.

| Device | I²C Address | Role |
| --- | --- | --- |
| U6 | 0x76 | Primary |
| U12 | 0x77 | Secondary |

Using two independent barometers provides an additional measurement source for altitude and apogee detection.

### SAM-M8Q — GNSS

The SAM-M8Q provides:

* Position
* Velocity
* Time

It is primarily used for:

* Recovery location
* Trajectory logging
* Flight-data analysis

> ⚠️ **High-altitude flight note:** Check the receiver's altitude and velocity limitations against the intended flight profile before use.

### INA226-Q1 — Power Monitoring

The INA226 is intended to measure:

* Bus voltage
* Current
* Power

> ⚠️ **Current status:** The INA226 is not currently connected to a shunt or bus. See [Known Issues](#known-issues--to-do-before-ordering).

### DS3231 — Real-Time Clock

The DS3231 provides an accurate real-time reference for timestamping logged flight data.

It is a clock rather than a flight sensor.

---

# 6. Protection and Reliability

## Implemented Protection

| Feature | Device / Implementation | Purpose |
| --- | --- | --- |
| Voltage supervision | TPS389033-Q1 | Monitors 3.3 V rail |
| CAN protection | TJA1051 | CAN bus fault tolerance |
| Ground planes | In1.Cu + In2.Cu | Noise reduction and signal return |
| GPS keepout | PCB rule area | Protects antenna performance |
| Local decoupling | 100 nF–1 µF capacitors  | Supply filtering |
| Pull-ups / biasing  | R14–R17 | Prevents floating control signals |

### Voltage Supervisor

**U8 — TPS389033-Q1**

The supervisor monitors the 3.3 V supply and controls the Teensy's ON/OFF line when the supply falls below the configured threshold.

> ⚠️ The Teensy 4.0 ON/OFF pin is not equivalent to a conventional hardware reset input. Verify that the intended supervisor behaviour is appropriate for the flight application.

### CAN Protection

**U5 — TJA1051**

The CAN transceiver provides built-in protection against bus faults and includes features such as thermal shutdown and TXD dominant-timeout protection.

> ⚠️ No external CAN ESD/TVS protection is currently fitted. Because J4 connects to an external cable, additional CAN protection should be considered.

### Ground Planes

In1.Cu and In2.Cu are maintained as solid ground planes to:

* Provide low-impedance return paths
* Reduce loop area
* Reduce EMI
* Improve signal integrity

### GPS Antenna Keepout

A dedicated keepout region is provided beneath the SAM-M8Q patch antenna to avoid copper, vias, and components interfering with GNSS performance.

---

## Protection Not Currently Implemented

The following protection features are absent or incomplete:

* ❌ Reverse-polarity protection
* ❌ Input fuse/PTC
* ❌ CAN external TVS/ESD protection
* ❌ microSD ESD protection
* ❌ Brown-out energy storage
* ❌ RTC backup battery
* ❌ GNSS backup supply
* ❌ Pyro/deployment protection circuitry

These should be reviewed according to the final system architecture and flight requirements.

---

# 7. Board Dimensions

| Parameter | Specification |
| --- | --- |
| Board size | **110.0 × 56.0 mm** |
| Board thickness | **1.6 mm** |
| Board shape | Rectangular |
| Component placement | Top side only |
| Mounting holes | 4 × Ø3.0 mm NPTH |
| Mounting-hole keepout | Ø6.5 mm |

### Mounting Hole Locations

Coordinates are measured from the **top-left corner** of the PCB:

| Hole | X | Y |
| ---- | ---: | ---: |
| H4 | 3.0 mm |  4.5 mm |
| H2 | 105.0 mm |  4.5 mm |
| H3 | 3.5 mm | 52.5 mm |
| H2 | 106.0 mm | 52.0 mm |

> ⚠️ The mounting holes are currently **not arranged on a perfectly rectangular pattern**. The bottom holes are offset by approximately 0.5–1.0 mm relative to the top holes. Consider standardising the mounting pattern before fabrication.

### Tall Components

| Component  | Approx. Height |
| --- | ---: |
| BZ1 buzzer | 9.5 mm |
| U4 SAM-M8Q | 6.3 mm |
| Teensy 4.0 | Depends on mounting method |

---

# 8. Teensy 4.0 Pin Map

| Teensy Pin | Signal | Connected Device |
| --- | --- | --- |
| 5 | BUZZER | BZ1 / ADXL375 INT1 / BMI088 INT3 ⚠️  |
| 6 | LED | D1 via R11 |
| 7 | ADXL_CS | ADXL375 CS |
| 8, 34 | BMI088 signals | BMI088 ⚠️ |
| 9, 33 | BMI088 INT2 | BMI088 ⚠️ |
| 10 | SD_CS | microSD |
| 11 | MOSI | microSD / ADXL375 |
| 12 | MISO | microSD / ADXL375 |
| 13 | SCK | microSD / ADXL375 |
| 14 (TX3) | GPS_RX | SAM-M8Q |
| 15 (RX3) | GPS_TX | SAM-M8Q |
| 16 (SCL1)  | I2C_SCL | BNO055 / BMP390 ×2 / DS3231 / INA226 |
| 17 (SDA1)  | I2C_SDA | BNO055 / BMP390 ×2 / DS3231 / INA226 |
| 22 (CTX1)  | CAN_TX | TJA1051 |
| 23 (CRX1)  | CAN_RX | TJA1051 |
| 26 (MOSI1) | BMI088_SDI | BMI088 |
| 27 (SCK1)  | BMI088_SCK | BMI088 |
| ON/OFF | nRESET | TPS3890 |
| 3V3 | +3.3 V | Board supply |
| GND | GND | Board ground |

⚠️ = requires review before fabrication.

---

# 9. I²C Address Map

| Device | Address | Configuration  |
| --- | --- | --- |
| BNO055 | 0x29 | COM3 = 3.3 V |
| BMP390 — U6  | 0x76 | SDO = GND |
| BMP390 — U12 | 0x77 | SDO = 3.3 V |
| DS3231 | 0x68 | Fixed |
| INA226 | **Undefined ⚠️** | A0/A1 floating |

---

# 10. Known Issues / To-Do Before Ordering

> ⚠️ **The current PCB should not be sent for fabrication until the following issues have been reviewed and resolved.**

## 10.1 Critical Functional Issues

### 1. GPS Power

The SAM-M8Q is currently powered through **R3 = 4.7 kΩ**.

This is likely to prevent the GPS from receiving sufficient supply current.

**Action:** Replace R3 with **0 Ω** or an appropriate ferrite bead.

---

### 2. GPS VCC_IO and V_BCKP

The following SAM-M8Q pins are currently unconnected:

* VCC_IO
* V_BCKP

**Action:** Connect VCC_IO appropriately and either connect V_BCKP to the intended backup supply or explicitly terminate it according to the application requirements.

---

### 3. CAN Transceiver Power

The TJA1051 currently has unconnected:

* VCC
* VIO
* GND / exposed pad

The design also does not currently provide the required CAN transceiver supply rail.

**Action:** Resolve the CAN power architecture before fabrication.

---

### 4. BMI088 Interface

The BMI088 connections require significant review.

Current concerns include:

* CSB2, SDO1, SDO2 and INT1 sharing a net
* CSB1 tied directly to GND
* SDO lines not correctly connected to the intended SPI MISO path
* INT2 shorting Teensy pins 9 and 33

**Action:** Re-check the complete BMI088 SPI and interrupt wiring against the datasheet and intended Teensy SPI peripheral.

---

### 5. Buzzer / Interrupt Conflict

The buzzer output currently shares a net with:

* ADXL375 INT1
* BMI088 INT3
* Teensy pin 5

This can cause electrical conflicts between the buzzer driver and sensor interrupt outputs.

**Action:** Assign the buzzer and sensor interrupts to independent nets. A transistor driver should also be considered for the buzzer.

---

### 6. ADXL375 Ground Connections

ADXL375 ground pins 4 and 5 are currently unconnected.

**Action:** Connect all required GND pins according to the datasheet.

---

### 7. BNO055 Interface Configuration

The current PS0/PS1 configuration may select an unintended communication protocol.

**Action:** Verify the PS0/PS1 configuration against the desired standard I²C operating mode.

---

### 8. INA226

The INA226 is currently incomplete:

* A0/A1 are floating
* VBUS is unconnected
* IN+ is unconnected
* IN− is unconnected
* No current-sense shunt is implemented

**Action:** Either complete the power-monitoring circuit or remove the INA226 from the design.

---

### 9. DS3231 Backup Supply

The DS3231 VBAT pin is currently floating.

**Action:** Either provide a backup battery or connect VBAT appropriately according to the intended operating mode.

---

## 10.2 Design Review Items

### I²C Pull-Ups

Multiple 4.7 kΩ pull-ups appear on the I²C bus.

The resulting parallel resistance may be unnecessarily low.

**Action:** Populate a single appropriate pull-up pair and mark redundant footprints as **DNP**.

### Unspecified Resistor Values

The following components have incomplete values:

* R5
* R6
* R9
* R10
* R11

**Action:** Specify the required resistance or mark the component as DNP.

### Teensy ON/OFF Behaviour

The TPS3890 drives the Teensy ON/OFF pin.

**Action:** Confirm that the resulting power-off behaviour is acceptable, as the ON/OFF input does not function as a conventional reset pin.

### TPS3890 SENSE Network

R18 = 240 kΩ is connected to the TPS3890 SENSE network.

**Action:** Verify that this resistor does not unintentionally shift the intended voltage threshold.

### Decoupling

Review local decoupling for:

* DS3231
* INA226
* TJA1051
* SAM-M8Q
* microSD

### Passive Package Sizes

The current design uses very small passive packages, including **01005** components and a **0201 LED**.

**Action:** Consider 0402 packages if manual assembly is expected.

---

# 11. PCB Housekeeping

Before generating manufacturing files:

* [ ] Re-annotate mounting holes — duplicate `H2` designators exist.
* [ ] Add/fix missing `H1` designator.
* [ ] Remove stray via around `(132.4, 5.8)`.
* [ ] Remove duplicate GND vias around `(171, 44)`.
* [ ] Verify all mounting-hole locations.
* [ ] Verify all silkscreen labels.
* [ ] Check component courtyard clearance.
* [ ] Run **Electrical Rules Check (ERC)**.
* [ ] Run **Design Rules Check (DRC)**.
* [ ] Resolve all critical DRC/ERC errors.
* [ ] Generate and inspect Gerbers before fabrication.

---

# 12. Pre-Fabrication Checklist

### Electrical

* [ ] Power architecture verified
* [ ] GPS power verified
* [ ] CAN power verified
* [ ] CAN termination verified
* [ ] BMI088 SPI verified
* [ ] BMI088 interrupts verified
* [ ] BNO055 protocol configuration verified
* [ ] ADXL375 grounding verified
* [ ] INA226 completed or removed
* [ ] DS3231 backup supply resolved
* [ ] Buzzer/interrupt conflict resolved
* [ ] Protection requirements reviewed

### PCB

* [ ] Stackup confirmed with manufacturer
* [ ] 1 oz copper specified on all layers
* [ ] Surface finish specified
* [ ] Blind via removed or fabrication capability confirmed
* [ ] Board dimensions verified
* [ ] Mounting pattern finalised
* [ ] Connector footprints verified
* [ ] Component clearances checked
* [ ] DRC passed
* [ ] ERC passed

### Documentation

* [ ] BOM updated
* [ ] Part numbers verified
* [ ] Connector specifications confirmed
* [ ] Sensor list updated
* [ ] Revision number updated
* [ ] Schematic revision updated
* [ ] PCB revision updated
* [ ] README updated
* [ ] Gerbers generated
* [ ] Gerbers reviewed

---

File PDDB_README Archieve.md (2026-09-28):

# PDDB 

## 1. Overview

The **Power Distribution & Driver Board (PDDB)** is a power-management and output-control PCB designed to distribute battery power, provide regulated low-voltage rails, communicate over CAN, and control external loads such as nichrome coils.

The board incorporates:

* Battery/power input connections
* High-current power distribution
* Fused input protection
* Buck-converter voltage regulation
* 3.3 V regulation
* CAN bus communication
* Current sensing
* MOSFET-based load switching
* Nichrome coil outputs
* External signal and ground connections

The design is implemented in **KiCad** and consists of both the schematic and PCB layout.

---

## 2. Project Files

| File | Description |
| --- | --- |
| `PDDB Schematic.kicad_pro` | KiCad project configuration |
| `PDDB Schematic.kicad_sch` | Electrical schematic |
| `PDDB Schematic.kicad_pcb` | PCB layout |
| `PDDB Schematic-backups/`  | KiCad automatic project backups |
| `.history/` | KiCad local history |

### Current Design Version

**Version:** v0.x — Development

> The exact release/version number should be updated when this revision is formally pushed to the repository.

---

# 3. Functional Architecture

The PDDB can be broadly divided into the following functional blocks:

```text
                 ┌──────────────────────┐
Battery Input ──►│ Input Protection     │
                 │ Fuse / Protection    │
                 └──────────┬───────────┘
                            │
                            ▼
                 ┌──────────────────────┐
                 │ Power Distribution   │
                 │ & Current Sensing    │
                 └───────┬───────┬──────┘
                         │       │
              ┌──────────┘       └──────────────┐
              ▼                                 ▼
      ┌───────────────┐                 ┌────────────────┐
      │ Buck Converter│                 │ Load Switching │
      │ LM25085       │                 │ MOSFETs        │
      └───────┬───────┘                 └───────┬────────┘
              │                                 │
              ▼                                 ▼
         Regulated Rails                  Nichrome Coils

              │
              ▼
      ┌───────────────┐
      │ CAN Interface │
      │ TJA1051T      │
      └───────────────┘
```

---

# 4. Power Regulation

## 4.1 Main Buck Converter

The primary switching regulator is:

**U1 — LM25085MY**

The LM25085 is used as the main buck-converter controller.

Associated components include:

| Reference | Value | Function |
| --- | ---: | --- |
| U1 | LM25085MY | Buck regulator controller |
| L1 | 1.2 µH | Output inductor |
| Rsen1 | 10 mΩ | Current-sense resistor |
| C5 | 33 µF | Output filtering |
| C2 | 100 µF | Bulk filtering |
| R6 | 3.32 kΩ | Feedback/control network |
| Radj1 | 2.55 kΩ | Adjustable regulation network |
| Radj2 | 2.55 kΩ | Adjustable regulation network |
| C3 | 470 nF | Filtering/compensation |

The exact regulated output voltage and maximum current should be confirmed against the latest power-budget calculations before fabrication.

---

## 4.2 3.3 V Regulation

**VR1 — LM3940IMP-3.3_NOPB**

The LM3940 is used to provide a regulated **3.3 V rail** for low-voltage circuitry.

Associated capacitor:

* **C4 — 3.3 µF**

The 3.3 V rail is intended for the board's low-voltage electronics and control/interface circuitry.

---

# 5. Input and Protection

The PDDB includes input protection to reduce the risk of damage caused by electrical faults.

## 5.1 Fuse

**F1 — Fuse**

The fuse provides overcurrent protection on the power input.

The final fuse rating should be selected based on:

* Maximum expected operating current
* Normal startup/inrush current
* Nichrome load current
* PCB trace/current capacity
* Connector current rating
* Power supply/battery specifications

**Fuse rating: TBD / confirm before release**

---

## 5.2 Reverse/Transient Protection

The design includes:

**D1 — Schottky diode**

The Schottky diode provides protection within the power-input/control circuitry.

The exact protection behaviour should be verified against the final schematic and intended fault cases before the production release.

---

## 5.3 Bulk and Local Decoupling

The board contains multiple capacitors for:

* Input bulk energy storage
* Switching regulator filtering
* Local supply decoupling
* Noise reduction

Relevant components include:

* C1 — 1.6 nF
* C2 — 100 µF
* C3 — 470 nF
* C4 — 3.3 µF
* C5 — 33 µF
* Cadj1 — 1 nF
* Cadj2 — 1 nF
* Cadj3 — 1 nF

---

# 6. CAN Communication

## CAN Transceiver

**U2 — TJA1051T**

The TJA1051T provides the physical-layer interface for CAN communication.

The board exposes:

* **CANH**
* **CANL**

The schematic also includes:

**R4 — 120 Ω**

This resistor is associated with CAN bus termination.

### CAN Connector

The CAN interface is exposed through the board's connector/interface circuitry.

The final system configuration should determine whether the board is intended to provide a permanent 120 Ω termination or whether termination should be selectable.

---

# 7. Load / Nichrome Control

The PDDB provides switched outputs for nichrome-based loads.

Two dedicated connectors are present:

| Reference | Label | Purpose |
| --- | --- | --- |
| J7 | `nichrome coil` | Nichrome load connection |
| J8 | `nichrome coil` | Nichrome load connection |

The load switching circuitry uses MOSFETs including:

* **Q2 — AO3400A**
* **Q3 — AO3400A**
* **U4 — CSD25402Q3A**

These devices provide electronic switching of the connected loads.

The exact continuous and peak current limits must be verified from:

1. MOSFET SOA/current rating
2. PCB copper capacity
3. Connector rating
4. Thermal performance
5. Nichrome resistance
6. Supply voltage

---

# 8. Connectors

The current schematic contains the following external connectors/interfaces.

| Reference | Label / Value | Purpose |
| --- | --- | --- |
| J1 | `Conn_01x02` | 2-pin external connection |
| J2 | `Battery and input` | Battery/power input |
| J3 | `Conn_01x01_Pin` | Single-pin connection |
| J4 | `Conn_01x02` | 2-pin external connection |
| J5 | `Battery and input` | Battery/power input |
| J6 | `Conn_01x01_Pin` | Single-pin connection |
| J7 | `nichrome coil` | Nichrome load output |
| J8 | `nichrome coil` | Nichrome load output |

### Connector Design Rationale

The connectors are provided to separate the major external interfaces of the PDDB:

* **Battery/input connectors** provide the primary power connection.
* **Nichrome connectors** provide dedicated high-current load connections.
* **2-pin connectors** provide signal/power connections where both signal and return are required.
* **Single-pin connectors** provide dedicated signal/test/auxiliary connections where a separate ground connection is not required at the connector.

> The exact mating connector part numbers should be added to the BOM before the PCB is released for manufacturing.

---

# 9. Current Sensing

The board contains:

**Rsen1 — 10 mΩ**

This low-value shunt resistor is used for current sensing within the power stage.

The shunt allows the voltage developed across the resistor to be used to determine current:

$$
I = \frac{V_{sense}}{R_{sense}}
$$

For the installed 10 mΩ resistor:

$$
I = \frac{V_{sense}}{0.010}
$$

Therefore, a 10 mV voltage drop corresponds to approximately:

$$
I = 1\,A
$$

and a 100 mV drop corresponds to:

$$
I = 10\,A
$$

The final measurable current range depends on the sensing circuitry and ADC/interface used by the overall system.

---

# 10. Sensor / Monitoring Interfaces

The current PDDB design should be treated as a **power and driver board rather than a dedicated sensor board**.

The following monitoring-related functionality is present:

| Function | Component / Interface | Status  |
| --- | --- | --- |
| Current sensing | Rsen1, 10 mΩ shunt | Present |
| CAN communication | U2, TJA1051T | Present |
| Supply voltage monitoring | External/system-dependent | Confirm |
| Temperature sensing | Not explicitly identified in current schematic | TBD |
| Current/voltage ADC | External MCU/system-dependent | TBD |

### Sensor List

Before the README is considered final, the project owner should confirm the complete system-level sensor list.

At minimum, document:

* Current sensor
* Voltage sensor
* Temperature sensor(s), if present
* Any external sensors connected through J1/J3/J4/J6
* CAN-connected sensors, if applicable

**Do not add a sensor to this list unless it is actually implemented or explicitly specified for the final system.**

---

# 11. PCB Stackup

The current KiCad PCB file does not contain a formal fabrication stackup definition.

The current board is therefore documented as:

**PCB type:** TBD
**Number of copper layers:** TBD
**Board thickness:** 1.6 mm nominal in the current KiCad board setup
**Copper weight:** TBD

### Recommended README entry after fabrication specification is confirmed

```text
Layer 1: Top Copper — TBD oz
Layer 2: Bottom Copper — TBD oz

Board thickness: 1.6 mm
Copper weight: TBD
Surface finish: TBD
Solder mask: TBD
Silkscreen: TBD
```

The final stackup should be confirmed with the PCB manufacturer before release.

---

# 12. Copper Weight

The copper weight has not been explicitly specified in the current KiCad PCB file.

**Current status: TBD**

Copper weight should be selected based on the maximum current carried by:

* Battery input traces
* Main power distribution paths
* Nichrome outputs
* Buck-converter power path

High-current traces should also be checked for:

* Trace width
* Temperature rise
* Via current capacity
* Connector current rating
* Copper thickness
* Continuous vs transient current

For the production release, the selected copper weight should be explicitly recorded here.

---

# 13. PCB Dimensions

The final mechanical dimensions should be recorded here once the Edge.Cuts outline has been finalized.

**Current board dimensions: TBD**

Required information:

| Parameter | Value |
| --- | --- |
| Length | TBD mm |
| Width | TBD mm |
| Thickness | 1.6 mm nominal |
| Mounting-hole diameter  | TBD mm |
| Mounting-hole locations | TBD |
| Connector clearance | TBD |
| Component height limit  | TBD |

The mechanical drawing should be checked before fabrication to ensure compatibility with the intended enclosure/system.

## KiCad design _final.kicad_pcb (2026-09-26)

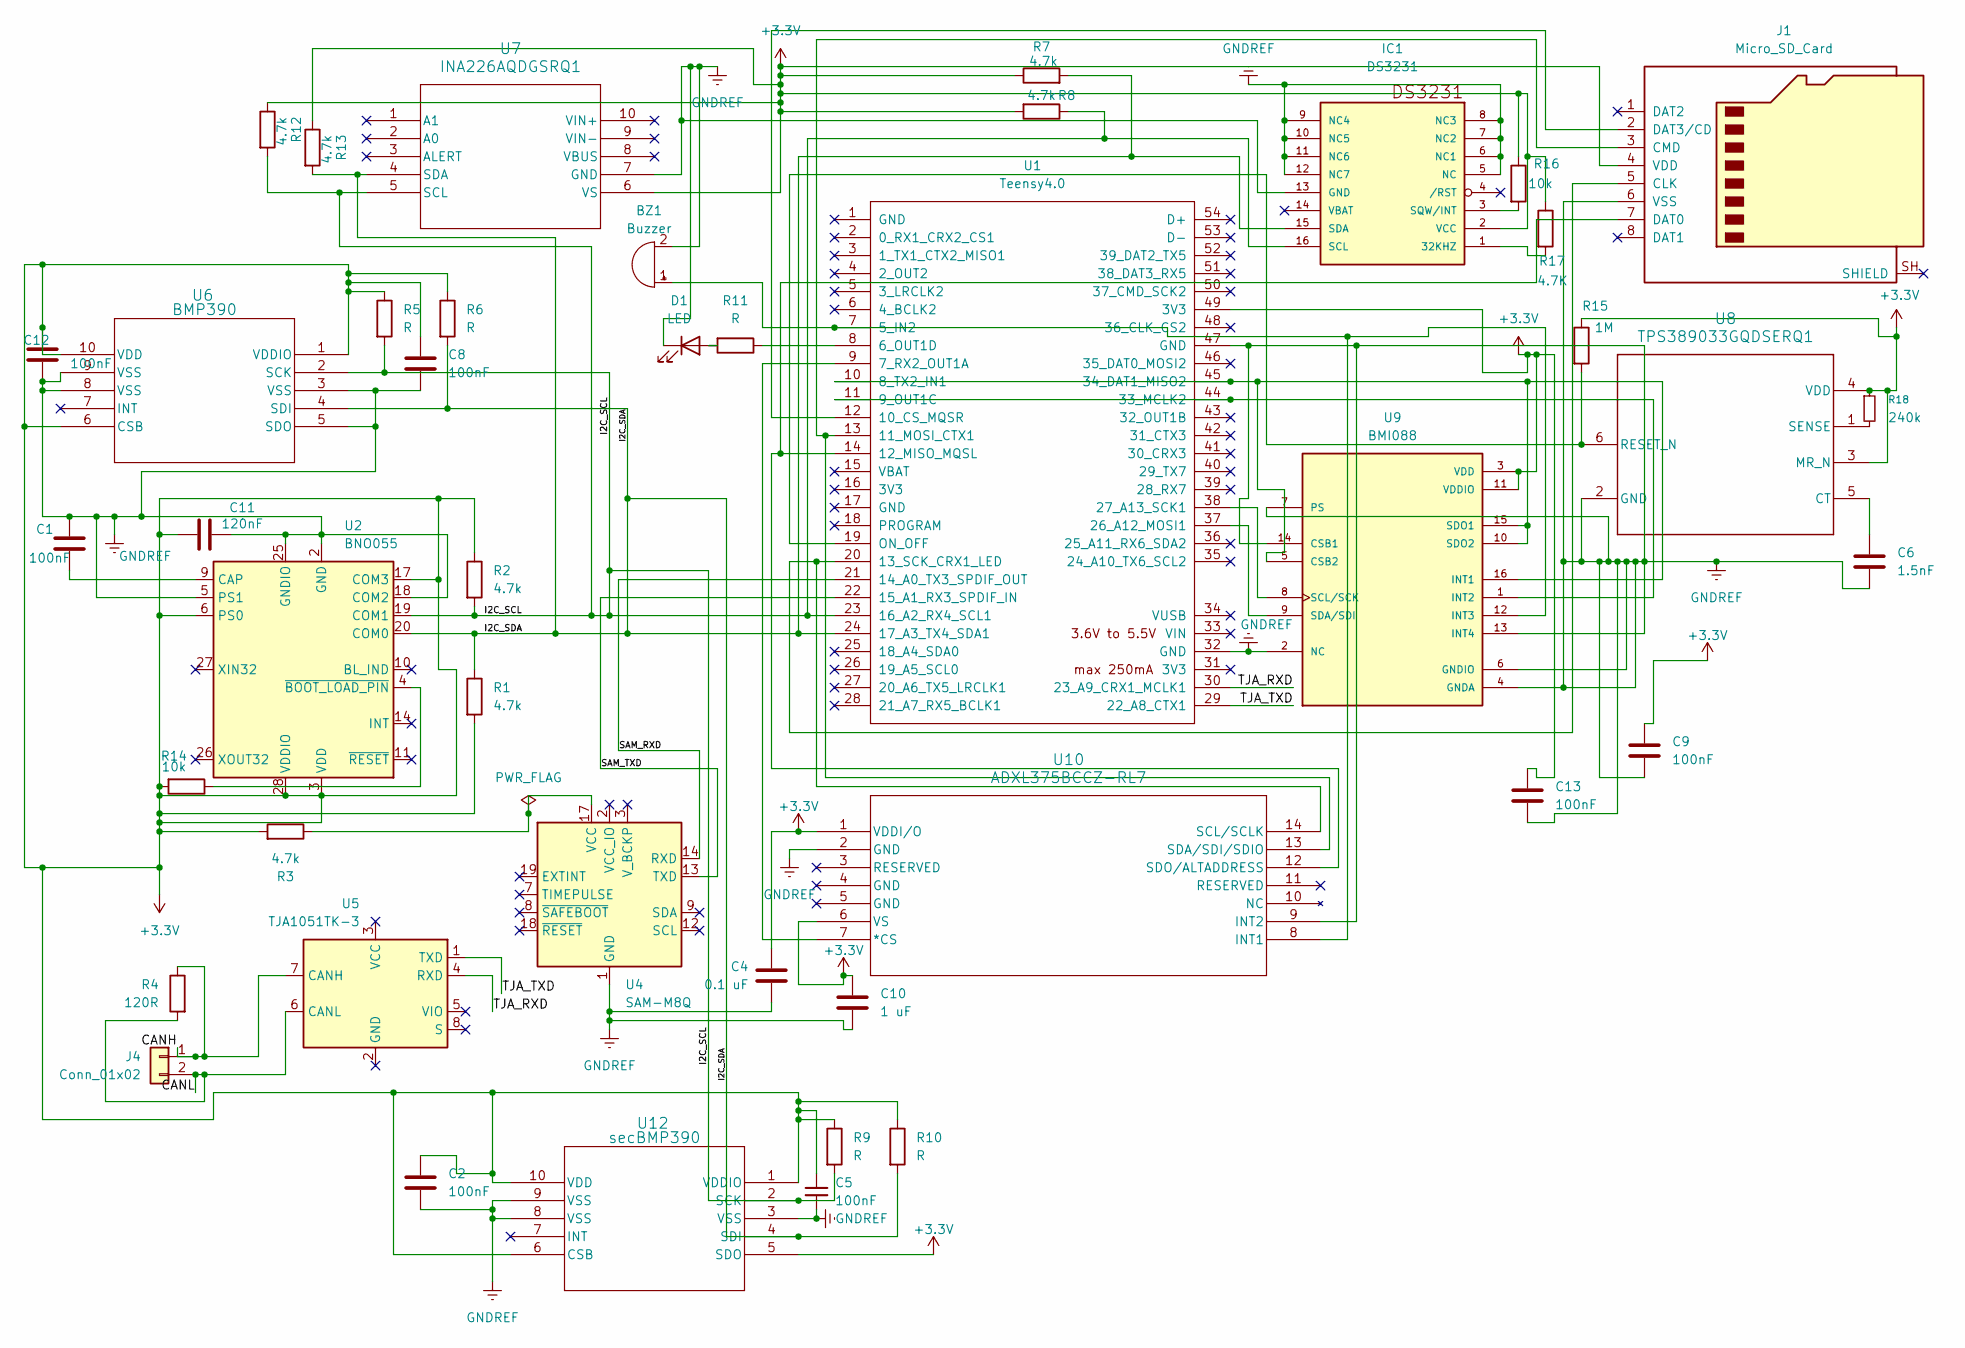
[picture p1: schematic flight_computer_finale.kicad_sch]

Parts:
BZ1: Buzzer; Buzzer_12x9.5RM7.6
C1, C2, C5, C8, C9, C12, C13: 100nF; C_01005_0402Metric
C4: 0.1 uF; C_01005_0402Metric
C6: 1.5nF; C_01005_0402Metric
C10: 1 uF; C_01005_0402Metric
C11: 120nF; C_01005_0402Metric
D1: LED; LED_0201_0603Metric
IC1: DS3231; 21-0042B_16_MXM
J1: Micro_SD_Card; microSD_HC_Wuerth_693072010801
J4: Conn_01x02; PinHeader_1x02_P2.54mm_Vertical
R1, R2, R3, R7, R8, R12, R13: 4.7k; R_01005_0402Metric
R4: 120R; R_01005_0402Metric
R5, R6, R9, R10, R11: R; R_01005_0402Metric
R14, R16: 10k; R_01005_0402Metric
R15: 1M; R_01005_0402Metric
R17: 4.7K; R_01005_0402Metric
R18: 240k; R_01005_0402Metric
U1: Teensy4.0; Teensy40_SMT
U2: BNO055; LGA-28_5.2x3.8mm_P0.5mm
U4: SAM-M8Q; ublox_SAM-M8Q
U5: TJA1051TK-3; HVSON-8-1EP_3x3mm_P0.65mm_EP1.6x2.4mm
U6: BMP390; 10LGA_2X2X0p75_BOS
U7: INA226AQDGSRQ1; DGS10_TEX
U8: TPS389033GQDSERQ1; DSE0006A
U9: BMI088; QFN_BMI085_BOS
U10: ADXL375BCCZ-RL7; LGA_CC-14-1_ADI
U12: secBMP390; 10LGA_2X2X0p75_BOS

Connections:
+3.3V: C2.1, C4.1, C5.1, C8.1, C9.1, C10.1, C11.1, C12.1, C13.1, IC1.2 (VCC), J1.4 (VDD), R1.2, R2.1, R3.2, R5.1, R6.1, R7.1, R8.2, R9.1, R10.1, R12.1, R13.1, R14.2, R15.1, R16.1, R17.1, R18.1, U1.49 (3V3), U2.3 (VDD), U2.6 (PS0), U2.17 (COM3), U2.28 (VDDIO), U6.1 (VDDIO), U6.6 (CSB), U6.10 (VDD), U7.6 (VS), U8.3 (MR_N), U8.4 (VDD), U9.3 (VDD), U9.11 (VDDIO), U10.1 (VDDI/O), U10.6 (VS), U12.1 (VDDIO), U12.5 (SDO), U12.6 (CSB), U12.10 (VDD)
/CANH: J4.1, R4.1, U5.7 (CANH)
/CANL: J4.2, R4.2, U5.6 (CANL)
/I2C_SCL: IC1.16 (SCL), R2.2, R5.2, R8.1, R9.2, R12.2, U1.23 (16_A2_RX4_SCL1), U2.19 (COM1), U6.2 (SCK), U7.5 (SCL), U12.2 (SCK)
/I2C_SDA: IC1.15 (SDA), R1.1, R6.2, R7.2, R10.2, R13.2, U1.24 (17_A3_TX4_SDA1), U2.20 (COM0), U6.4 (SDI), U7.4 (SDA), U12.4 (SDI)
/SAM_RXD: U1.21 (14_A0_TX3_SPDIF_OUT), U4.14 (RXD)
/SAM_TXD: U1.22 (15_A1_RX3_SPDIF_IN), U4.13 (TXD)
/TJA_RXD: U1.30 (23_A9_CRX1_MCLK1), U5.4 (RXD)
/TJA_TXD: U1.29 (22_A8_CTX1), U5.1 (TXD)
GNDREF: BZ1.2 (-), C1.1, C2.2, C4.2, C5.2, C6.2, C8.2, C9.2, C10.2, C11.2, C12.2, C13.2, D1.1 (K), IC1.5 (NC), IC1.6 (NC1), IC1.7 (NC2), IC1.8 (NC3), IC1.9 (NC4), IC1.10 (NC5), IC1.11 (NC6), IC1.12 (NC7), IC1.13 (GND), J1.6 (VSS), U1.32 (GND), U1.47 (GND), U2.2 (GND), U2.5 (PS1), U2.18 (COM2), U2.25 (GNDIO), U4.1 (GND), U4.4 (GND), U4.5 (GND), U4.6 (GND), U4.10 (GND), U4.11 (GND), U4.15 (GND), U4.16 (GND), U4.20 (GND), U6.3 (VSS), U6.5 (SDO), U6.8 (VSS), U6.9 (VSS), U7.7 (GND), U8.2 (GND), U9.2 (NC), U9.4 (GNDA), U9.6 (GNDIO), U9.7 (PS), U9.13 (INT4), U9.14 (CSB1), U10.2 (GND), U10.9 (INT2), U12.3 (VSS), U12.8 (VSS), U12.9 (VSS)
unnamed: BZ1.1 (+), U1.7 (5_IN2), U9.12 (INT3), U10.8 (INT1)
unnamed: D1.2 (A), R11.2
unnamed: IC1.1 (32KHZ), R17.2
unnamed: IC1.3 (SQW/INT), R16.2
unnamed: J1.5 (CLK), U1.20 (13_SCK_CRX1_LED), U10.14 (SCL/SCLK)
unnamed: J1.3 (CMD), U1.13 (11_MOSI_CTX1), U10.13 (SDA/SDI/SDIO)
unnamed: J1.7 (DAT0), U1.14 (12_MISO_MQSL), U10.12 (SDO/ALTADDRESS)
unnamed: J1.2 (DAT3/CD), U1.12 (10_CS_MQSR)
unnamed: R11.1, U1.8 (6_OUT1D)
unnamed: U1.9 (7_RX2_OUT1A), U10.7 (*CS)
unnamed: U1.37 (26_A12_MOSI1), U9.9 (SDA/SDI)
unnamed: U1.38 (27_A13_SCK1), U9.8 (SCL/SCK)
unnamed: U1.11 (9_OUT1C), U1.44 (33_MCLK2), U9.1 (INT2)
unnamed: U1.10 (8_TX2_IN1), U1.45 (34_DAT1_MISO2), U9.5 (CSB2), U9.10 (SDO2), U9.15 (SDO1), U9.16 (INT1)
unnamed: R15.2, U1.19 (ON_OFF), U8.6 (RESET_N)
unnamed: C1.2, U2.9 (CAP)
unnamed: R14.1, U2.4 (~BOOT_LOAD_PIN)
unnamed: R3.1, U4.17 (VCC)
unnamed: C6.1, U8.5 (CT)
unnamed: R18.2, U8.1 (SENSE)

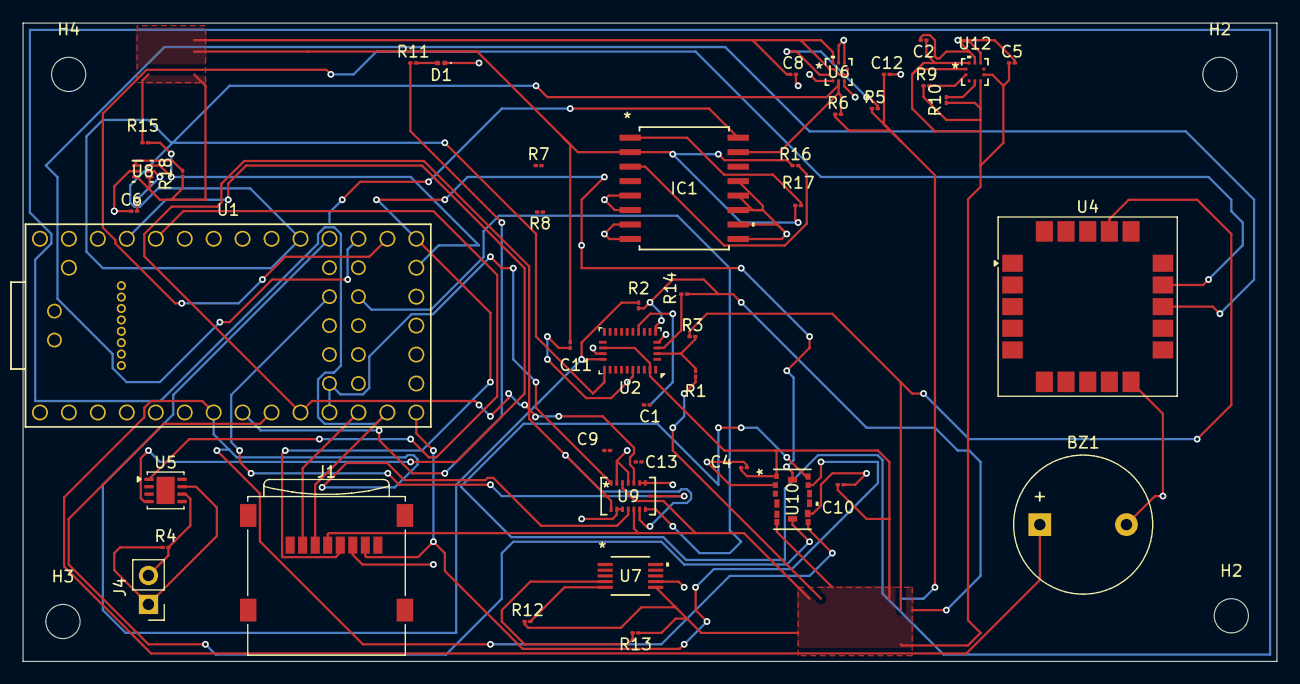
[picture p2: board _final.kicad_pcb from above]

Board: 4 copper layers, 110.0 x 56.0 mm, 48 parts (0 on the bottom side), 30 nets.

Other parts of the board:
H2, H2#2, H3, H4: MountingHole_3mm

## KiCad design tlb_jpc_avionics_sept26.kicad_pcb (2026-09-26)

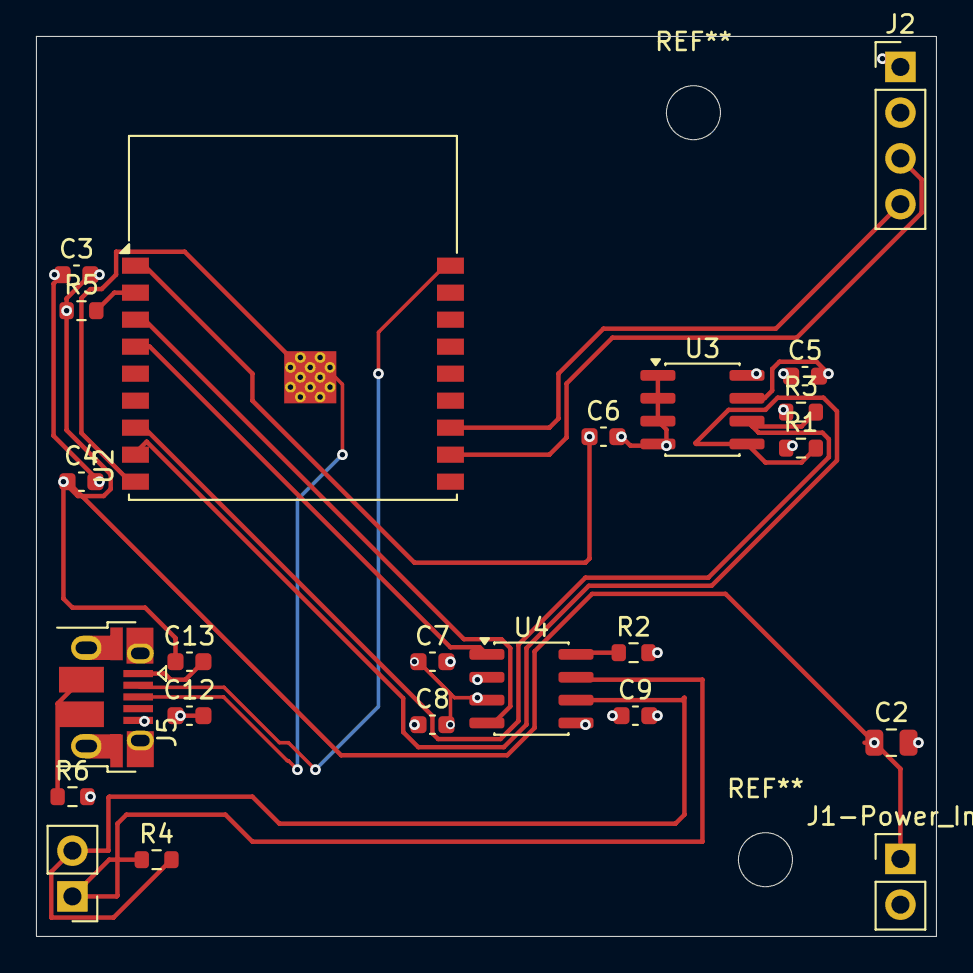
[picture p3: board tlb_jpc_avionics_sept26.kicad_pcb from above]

Board: 4 copper layers, 50.0 x 50.0 mm, 23 parts (0 on the bottom side), 18 nets.

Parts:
C2: 33u; C_0805_2012Metric
C3, C4, C5, C6, C8, C12: 0.1 uF; C_0603_1608Metric
C7, C9, C13: 0.1uF; C_0603_1608Metric
J1-Power_In1, J3: Conn_01x02; PinHeader_1x02_P2.54mm_Vertical
J2: Light_APRS; PinHeader_1x04_P2.54mm_Vertical
J5: USB_B_Micro; USB_Micro-B_Amphenol_10103594-0001LF_Horizontal
R1, R3: 4.7k; R_0603_1608Metric
R2, R5: 10kR; R_0603_1608Metric
R4: 120R; R_0603_1608Metric
R6: 0; R_0603_1608Metric
U2: ESP32-C3; ESP32-C3-WROOM-02
U3: 24LC256; SOIC-8_3.9x4.9mm_P1.27mm
U4: TJA1051TK-3; SOIC-8_3.9x4.9mm_P1.27mm

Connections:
+3V3: C2.1, C3.2, C4.1, C5.1, C6.1, C9.1, C13.1, J1-Power_In1.1, J2.1, R1.1, R3.1, R5.1, U2.1 (3V3), U3.8 (VCC), U4.5 (VIO)
+5V: C7.1, C8.2, U4.3 (VCC)
/CANH: J3.1, R4.1, U4.7 (CANH)
/CANL: J3.2, R4.2, U4.6 (CANL)
/CANRX: U2.3 (IO4), U4.4 (RXD)
/CANTX: U2.4 (IO5), U4.1 (TXD)
/RX0: J2.4, U2.12 (IO21/TXD)
/SCL: R3.2, U2.7 (IO8), U3.6 (SCL)
/SDA: R1.2, U2.8 (IO9), U3.5 (SDA)
/TX0: J2.3, U2.11 (IO20/RXD)
D+: J5.e (D+_3), U2.19 (GND)
D-: J5.2 (D-_2), U2.18 (IO0)
GND: C2.2, C3.1, C4.2, C5.2, C6.2, C7.2, C8.1, C9.2, C12.1, C12.2, J1-Power_In1.2, J2.2, J5.5 (GND_5), R2.2, R6.2, U3.1 (A0), U3.2 (A1), U3.3 (A2), U3.4 (GND), U3.7 (WP), U4.2 (GND)
unnamed: U2.9 (GND), U2.19 (GND)
unnamed: J5.6 (Shield_6), R6.1
unnamed: C13.2, J5.1 (VBUS_1)
unnamed: R5.2, U2.2 (EN)
unnamed: R2.1, U4.8 (S)

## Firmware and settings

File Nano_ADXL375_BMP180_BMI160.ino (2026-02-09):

// Arduino Nano I2C:
// SDA → A4
// SCL → A5

// BMI160:
// Vin → 3.3V
// GND → GND
// SDA → A4
// SCL → A5

// BMP180:
// Vin → 3.3V
// GND → GND
// SDA → A4
// SCL → A5

// ADXL375:
// Vin → 3.3V
// GND → GND
// SDA → A4
// SCL → A5

#include <Wire.h>
#include <Adafruit_Sensor.h>
#include <Adafruit_BMP085.h>
#include <BMI160Gen.h>


Adafruit_BMP085 bmp;

// kalman filter structure
struct Kalman {
  float x;      // state
  float p;      // uncertainty
  float q;      // process noise
  float r;      // measurement noise
};

Kalman kalAlt = {0, 1, 0.01, 1};
Kalman kalRoll = {0, 1, 0.01, 0.5};
Kalman kalPitch = {0, 1, 0.01, 0.5};

float kalmanUpdate(Kalman &k, float measurement) {
  k.p += k.q;
  float kGain = k.p / (k.p + k.r);
  k.x += kGain * (measurement - k.x);
  k.p *= (1 - kGain);
  return k.x;
}

// variable definitions
int accXi, accYi, accZi;
int gyroXi, gyroYi, gyroZi;
float rollAcc, pitchAcc;
float altitude;
unsigned long lastTime;
float accX, accY, accZ;
float gyroX, gyroY, gyroZ;

// boring setup ew
const float LOOP_DT = 0.01; // 100 Hz fixed timestep
unsigned long lastLoopMicros = 0;

// ADXL375 gyro bias
float gyroBiasX = 0;
float gyroBiasY = 0;
float gyroBiasZ = 0;

void calibrateGyro() {
  const int samples = 50;
  float sx = 0, sy = 0, sz = 0;

  for (int i = 0; i < samples; i++) {
    BMI160.readGyro(gyroXi, gyroYi, gyroZi);
    sx += gyroXi;
    sy += gyroYi;
    sz += gyroZi;
    delay(5);
  }

  gyroBiasX = sx / samples;
  gyroBiasY = sy / samples;
  gyroBiasZ = sz / samples;
}

void setup() {
  Serial.begin(1000);
  Wire.begin();   // A4 = SDA, A5 = SCL

//detect BMI160 connected?
  if (!BMI160.begin(BMI160GenClass::I2C_MODE)) {
    Serial.println("BMI160 not detected");
    while (1);
  }

  BMI160.setGyroRange(250);
  BMI160.setAccelerometerRange(2);

  calibrateGyro();

//detect BMP180 connected?
  if (!bmp.begin()) {
    Serial.println("BMP180 not detected");
    while (1);
  }

  lastTime = micros();
  Serial.println("Sensors initialized");
}

// for entire flight
void loop() {
  byte error, address;
  int nDevices = 0;

  for (address = 1; address < 127; address++) {
    Wire.beginTransmission(address);
    error = Wire.endTransmission();

    if (error == 0) {
      Serial.print("I2C device found at 0x");
      Serial.println(address, HEX);
      nDevices++;
    }
  }

  if (nDevices == 0)
    Serial.println("No I2C devices found");

  delay(2000);

  unsigned long now = micros();
  if (now - lastTime < 10000) return;
  lastTime += 10000;

  float dt = LOOP_DT;

  //read BMI160 
  BMI160.readAccelerometer(accXi, accYi, accZi);
  BMI160.readGyro(gyroXi, gyroYi, gyroZi);

  gyroX -= gyroBiasX;
  gyroY -= gyroBiasY;
  gyroZ -= gyroBiasZ;

  // convert to g and deg/s
  accX = accXi / 16384.0;   // g
  accY = accYi / 16384.0;
  accZ = accZi / 16384.0;

  gyroX = gyroXi / 131.0;   // deg/s
  gyroY = gyroYi / 131.0;
  gyroZ = gyroZi / 131.0;

// accelerometer angles
  rollAcc = atan2(accY, accZ) * 180 / PI;
  pitchAcc = atan2(-accX, sqrt(accY * accY + accZ * accZ)) * 180 / PI;

// gyro 
  kalRoll.x += gyroX * dt;
  kalPitch.x += gyroY * dt;

// kalman type shi
  float roll = kalmanUpdate(kalRoll, rollAcc);
  float pitch = kalmanUpdate(kalPitch, pitchAcc);

// to read BMP180
  float pressure = bmp.readPressure() / 100.0; // hPa
  altitude = bmp.readAltitude(1013.25);
  altitude = kalmanUpdate(kalAlt, altitude);

// Allan Variance
  Serial.print(gyroX);
  Serial.print(",");
  Serial.print(gyroY);
  Serial.print(",");
  Serial.println(gyroZ);

// for the rotating part
  static float velX = 0, velY = 0, velZ = 0;
  static float posX = 0, posY = 0, posZ = 0;

  float rollRad = roll * PI / 180.0;
  float pitchRad = pitch * PI / 180.0;

// gravity-compensated acceleration - compute roll and pitch
  float accWorldX = accX * cos(pitchRad) + accZ * sin(pitchRad);
  float accWorldY = accY * cos(rollRad) - accZ * sin(rollRad);
  float accWorldZ = accZ * cos(rollRad) * cos(pitchRad) - 1.0; // remove 1g

  velX += accWorldX * 9.81 * dt;
  velY += accWorldY * 9.81 * dt;
  velZ += accWorldZ * 9.81 * dt;

  posX += velX * dt;
  posY += velY * dt;
  posZ += velZ * dt;

  float altError = altitude - posZ;
  posZ += 0.05 * altError;
  velZ += 0.01 * altError;

// give me da output :D
  Serial.print("Alt(m): ");
  Serial.print(altitude, 2);
  Serial.print(" | Roll: ");
  Serial.print(roll, 2);
  Serial.print(" | Pitch: ");
  Serial.println(pitch, 2);
}

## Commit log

2026-02-09 Add files via upload
    - managed to debug code for kalman filter and execute Allan variance
    - code still doesn't run properly and pure gibberish is seen in serial plotter along with the error wire.end transmission failed. However, it compiles. Just doesn't plot data or show change in attitude and pressure like we wanted it to.
    [Nano_ADXL375_BMP180_BMI160.ino]
2026-09-20 Add files via upload
    These are the schematic and PCB files for the TLB (Telemetry and Logging Board).
    [tlb_jpc_avionics.kicad_sch, tlb_jpc_avionics_sept20.kicad_pcb]
2026-09-26 D+/D- done now
    [tlb_jpc_avionics_sept26.kicad_pcb]
2026-09-26 D+/D- done schematic
    [tlb_jpc_avionics_sep26.kicad_sch]
2026-09-26 Add files via upload
    ReadMe is in the files uploaded
    [_final.kicad_pcb, flight_computer_finale.kicad_sch]
2026-10-01 Rename PDDB Schematic (2).zip to PDDB Schematic_Archieve.zip
